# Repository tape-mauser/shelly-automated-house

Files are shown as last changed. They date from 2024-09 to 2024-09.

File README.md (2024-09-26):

# Shelly Automated Exhibition House

The project is fully completed and operational. However, the documentation is still a work in progress. We are actively working on providing detailed instructions, schematics, and additional information. Please stay tuned for updates.

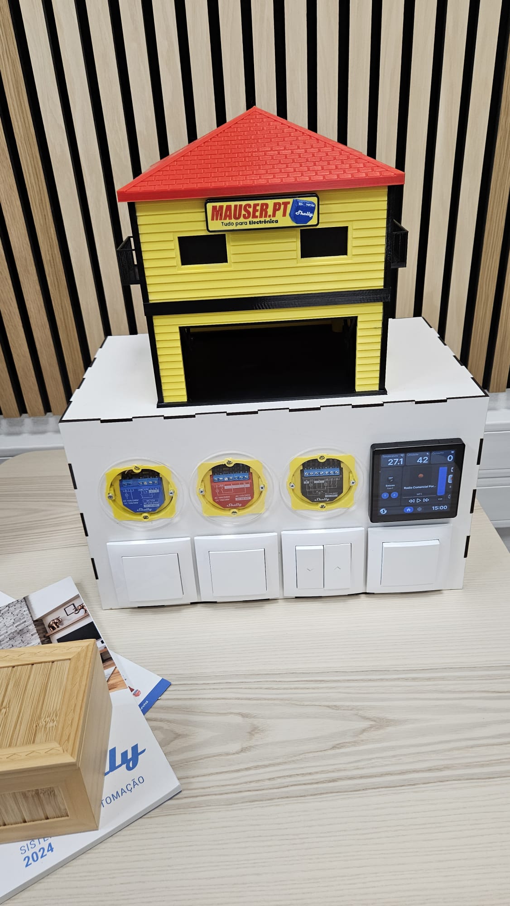
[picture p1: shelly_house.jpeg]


Welcome to the Automated Exhibition House project! This repository showcases a fully functional smart home setup using Shelly modules. The house is equipped with four Shelly modules, which control the gate, shutters, and lighting, providing an automated and seamless experience.

Watch the demonstration video below:

[Demo Video](https://youtu.be/CE9VABJTA8k)

## Project Overview
This project demonstrates the integration of IoT technology in a modern exhibition house setting. The key features include:

Automated Gate: The gate can be controlled remotely, allowing for easy access and enhanced security.
Smart Shutters: Control the shutters automatically or remotely to adjust the light and privacy levels in the house.
Lighting Control: The house's lighting system is fully automated, providing customized lighting scenes based on time or user preferences.
Modules Used
### Shelly plus 1PM: Utilized for the lighting system, enabling smooth dimming and on/off control.
### Shelly plus 2PM: Deployed for managing the shutters, allowing for both automation and manual control.
### Shelly Plus 1: Used to control the gate, ensuring precise and reliable operation. 
### Shelly wall display: Provides a user-friendly interface for monitoring and controlling the entire system from a central location.

## How It Works
The house is connected through a local Wi-Fi network, where each Shelly module is configured via the Shelly app or a home automation platform like Home Assistant. Users can interact with the system through their smartphones or integrate it with voice assistants for hands-free control.

## Installation
Hardware Setup: Install the Shelly modules in the designated locations (gate, shutters, lights).
Configuration: Connect the modules to your Wi-Fi network using the Shelly app.
Automation: Set up automation rules and schedules based on your preferences.
Monitoring: Use the Shelly app or a home automation dashboard to monitor and control the system.
Contributing
We welcome contributions to enhance this project! Feel free to fork the repository, submit issues, or open pull requests.

## BOM

| Item | Quantity | Description | Size | Supplier | Link |
|:---|:---:|:---|:---:|:---:|:---:|
| Base | 1 | MDF | 1100x500x3mm | NA | |
| Dry Wall Box | 8 | electrical dry wall box | NA | Mauser.pt | https://mauser.pt/catalog/product_info.php?products_id=302-0743 |
| Shelly plus 2PM | 1 | Shelly plus 2PM | NA | Mauser.pt  |https://mauser.pt/catalog/product_info.php?products_id=095-0483 |
| Shelly plus 1PM | 1 | Shelly plus 1PM | NA | Mauser.pt |https://mauser.pt/catalog/product_info.php?products_id=096-3331 |
| Shelly plus 1 | 1 | Shelly plus 1 | NA | Mauser.pt |https://mauser.pt/catalog/product_info.php?products_id=096-3327 |
| Shelly wall display | 1 | Shelly wall display | NA | Mauser.pt  |https://mauser.pt/catalog/product_info.php?products_id=302-3545 |
| Relay 230v | 4 | Relay 230v | NA | Mauser.pt |https://mauser.pt/catalog/product_info.php?products_id=083-0127|
| Node mcu esp32 |  1 |  Node mcu esp32 | NA |Mauser.pt |https://mauser.pt/catalog/product_info.php?products_id=096-7620|
| Power Supply | 1 |  Power Supply | NA | Mauser.pt | https://mauser.pt/catalog/product_info.php?products_id=035-2961 |
| IEC panel | 1 |  IEC panel | NA | Mauser.pt | https://mauser.pt/catalog/product_info.php?products_id=011-0459 |
| Power cord | 1 | Power cord | NA |Mauser.pt | https://mauser.pt/catalog/product_info.php?products_id=047-2090|
|  Blue Wire | 10MTR |Blue Wire | 1,5mm | Mauser.pt |  https://mauser.pt/catalog/product_info.php?products_id=016-0413  |
| Black Wire | 10MTR |  Black Wire | 1,5mm | Mauser.pt | https://mauser.pt/catalog/product_info.php?cPath=1874_56_646_2747_3511&products_id=016-0414 |
| Yellow/green Wire | 0,5MTR | Yellow/green Wire | 1,5mm | Mauser.pt | https://mauser.pt/catalog/index.php?cPath=1874_56_646_2747_3511 |
| 3Pair alarm cable | 10MTR | 3Pair alarm cable | 0,22mm/0,75mm  |  Mauser.pt |https://mauser.pt/catalog/product_info.php?cPath=1874_56_1504&products_id=016-0275  |
| Wire terminal | 30 | Wire terminal | 1,5mm | Mauser.pt | https://mauser.pt/catalog/product_info.php?products_id=011-0529 |
| servo motor | 2 | Servo Motor | | Mauser.pt | https://mauser.pt/catalog/product_info.php?products_id=096-6268 |
| Led strip | 1 | Led Strip | | Mauser.pt | https://mauser.pt/catalog/product_info.php?products_id=306-5426 |
| Belt | 1 | Servo Belt gate | |  Mauser.pt | https://mauser.pt/catalog/product_info.php?products_id=037-1095 |
| Pressure switch |  1 | (gate) | | Mauser.pt | https://mauser.pt/catalog/product_info.php?cPath=570_572_855_3342_1007_3326&products_id=302-1632 |
| Light switch |  2 | (lights) | | Mauser.pt | https://mauser.pt/catalog/product_info.php?products_id=302-1503 |
| Shutters switch |  1 | (shutters) | | Mauser.pt | https://mauser.pt/catalog/product_info.php?products_id=302-1530 |
| Shutters key | 1 | | | Mauser.pt | https://mauser.pt/catalog/product_info.php?cPath=570_572_855_3342_1008_3338&products_id=302-1531 |
| Switch key | 3 | | | Mauser.pt | https://mauser.pt/catalog/product_info.php?products_id=302-1504 |
| Switch frame | 1 | | | Mauser.pt | https://mauser.pt/catalog/product_info.php?products_id=302-1513 |
| Transparent cover | 1 | 3 covers to prevent electric shock|400x100x3mm| NA |  |
| Fundação Lateral | 1 | 3d printed Part |  160gr | NA |  |
| Paredes RC com portão e porta | 1 | 3d printed Part | 280gr | NA |  |
| Chão | 1 | 3d printed Part | 120gr | NA |  |
| Paredes com Janelas e varandas | 1 |3d printed Part | 340gr |NA |  |
| Telhado | 1 | 3d printed Part | 550gr | NA |  |
| Suporte de servo fundo | 1 | 3d printed Part | 15gr | NA |  |
| Portao casa impressa | 1 |  3d printed Part | 15gr | NA |  |
| cobertura portao | 1 | 3d printed Part | 15gr | NA |  |
| Varanda | 2 |3d printed Part | 20gr | NA |  |
| Porta | 1 | 3d printed Part | 10gr | NA |  |
| janela interior estores | 2 | 3d printed Part | 10gr | NA |  |
| janela pequena | 2 | 3d printed Part multicolor | 20gr | NA |  |
| janela grande | 1 | 3d printed Part multicolor | 20gr | NA |  |
| estore | 1 | 3d printed Part | 10gr | NA |  |
| reclame | 1 | 3d printed Part multicolor | 20gr | NA |  |
| polia | 1 | 3d printed Part | 5gr | NA |  |
| polia servo | 2 | 3d printed Part | 5gr | NA |  |
|suporte de shelly | 3 | 3d printed Part | 35gr | NA |  |
|cantos | 8 | 3d printed Part | 10gr | NA |  |
|M3 Screws | 8 | | 16mm | NA |  |
|M3 Nuts | 4 | | | NA |  |

## 230v diagram

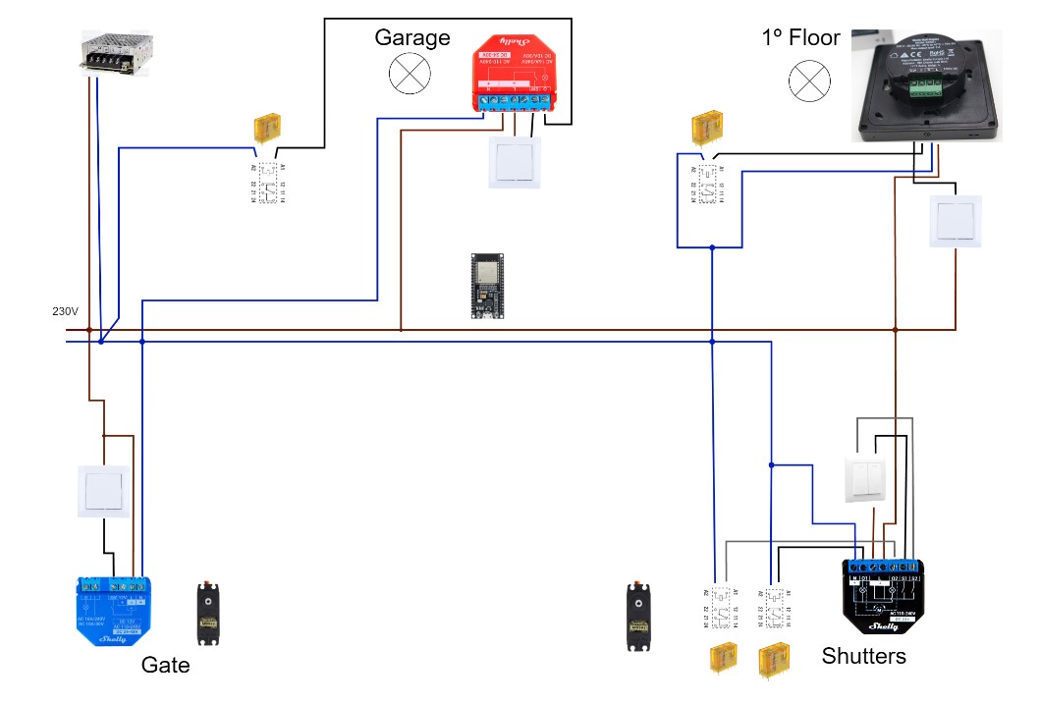
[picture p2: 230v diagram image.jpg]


You can view or download the full documentation in [this PDF file](./230v_shelly_diagram.pdf).

## 5v diagram

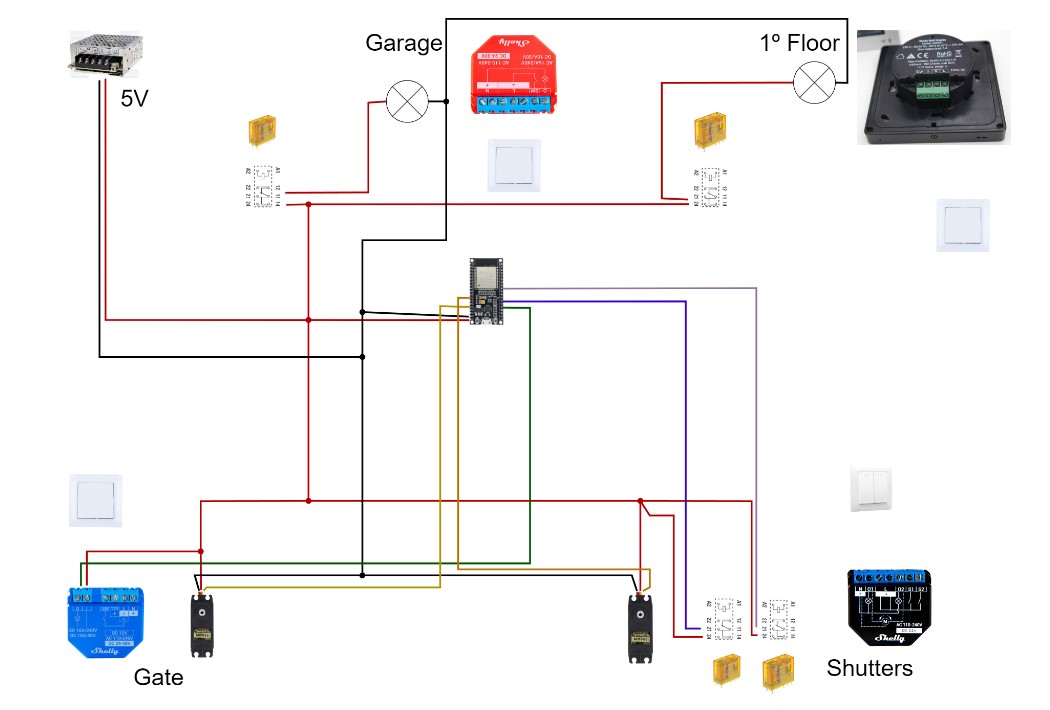
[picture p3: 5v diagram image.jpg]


You can view or download the full documentation in [this PDF file](./5v_shelly_diagram.pdf).

## ESP32 Code

use the ESP32servo by Kevin Harrington, John K. Bennett V 1.2.1  library
and esp32 by Espressif Systems V 2.0.17 Board manager 

ESP32 Dev Module

## License
This project is licensed under the MIT License. See the LICENSE file for more details.

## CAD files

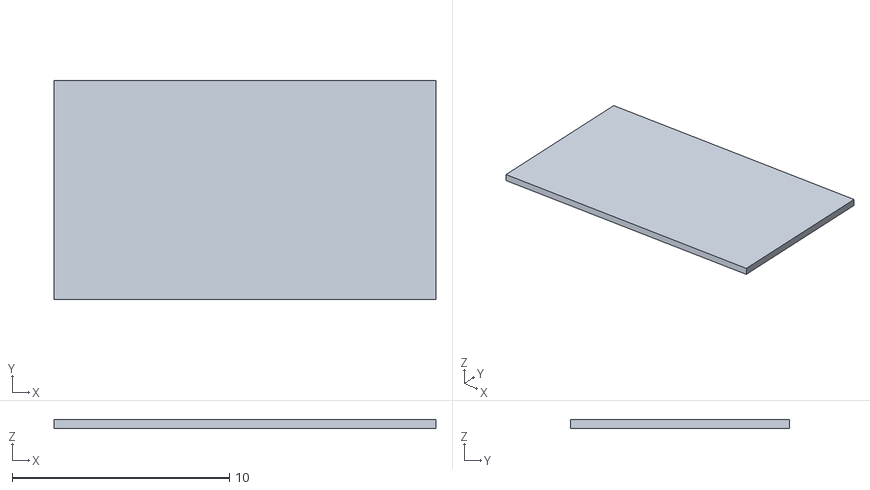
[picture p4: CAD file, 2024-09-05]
Multicolor STL's/Janela interior estores/Janela_interior_estores_Janela_interior_estores v1_Component1_1_Body3.stl
17.6 x 10.1 x 0.4

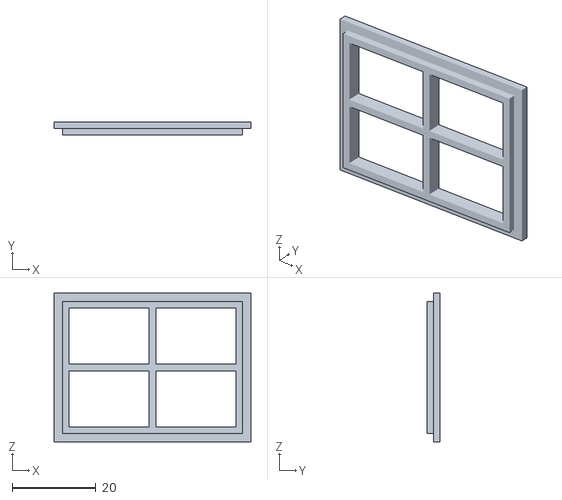
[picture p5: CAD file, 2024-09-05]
Multicolor STL's/janela pequena/janela pequena_janela pequena v2_Body1.stl
47.0 x 3.20 x 35.5

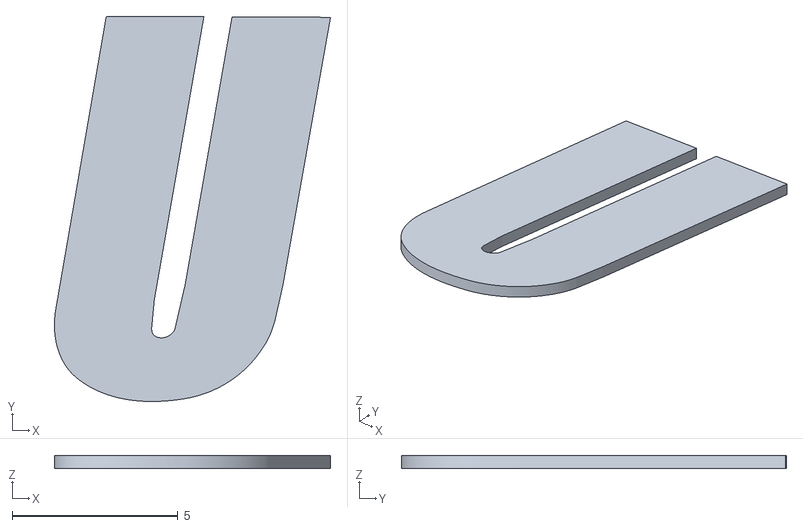
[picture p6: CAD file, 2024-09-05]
Multicolor STL's/reclame/reclame casa_reclame casa v2_Vermelho_1_Body2.stl
8.33 x 11.6 x 0.4

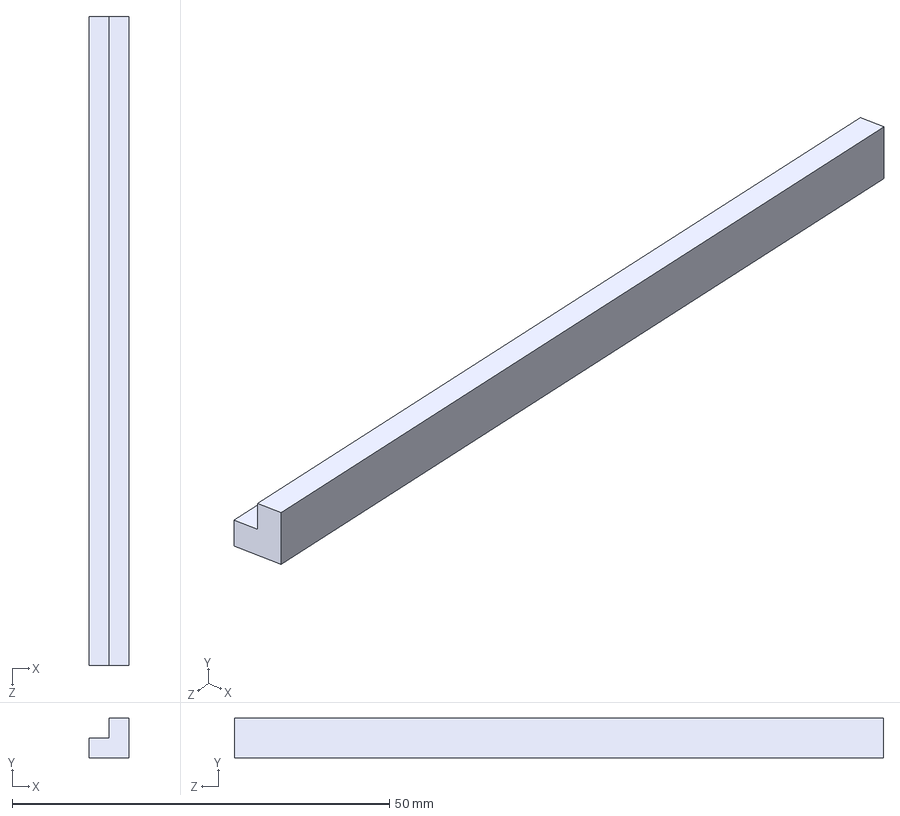
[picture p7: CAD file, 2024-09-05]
STEP's/cantos.STEP
5.25 x 5.25 x 86.0 mm

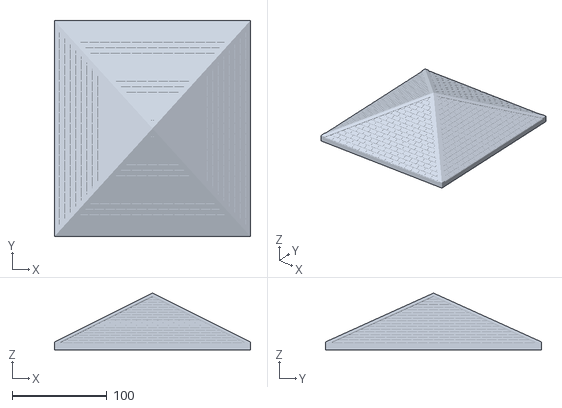
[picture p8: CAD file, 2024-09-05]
STL's/telhado.STL
206.8 x 227.8 x 60.0

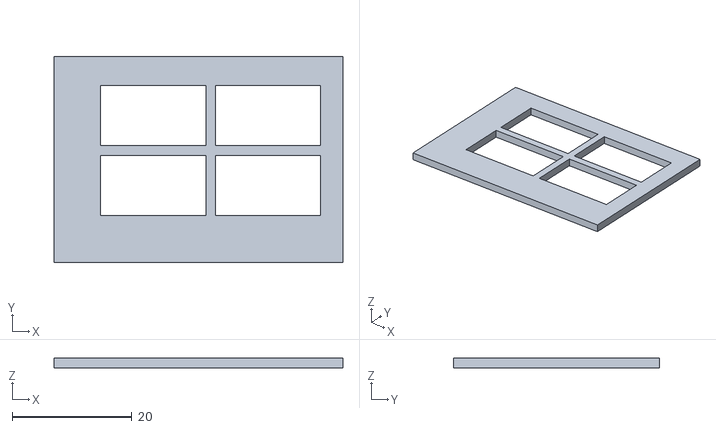
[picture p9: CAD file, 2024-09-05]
Multicolor STL's/Janela interior estores/Janela_interior_estores_Janela_interior_estores v1_Body1.stl
48.3 x 34.4 x 1.60

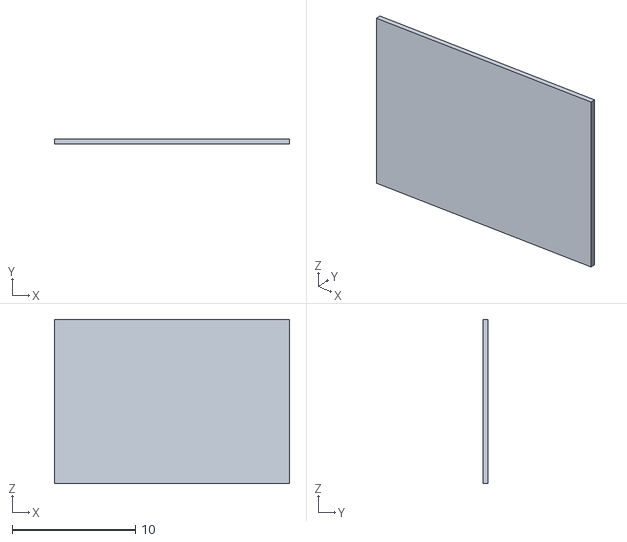
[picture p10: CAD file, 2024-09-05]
Multicolor STL's/janela pequena/janela pequena_janela pequena v2_Component1_1_Body4.stl
19.1 x 0.4 x 13.3

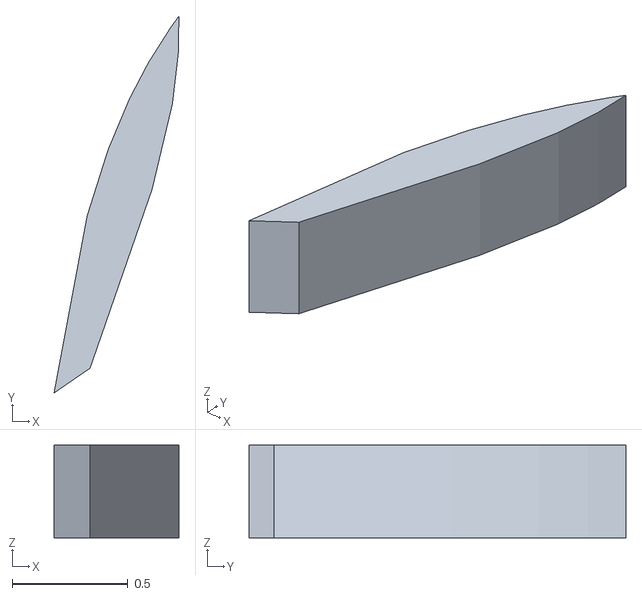
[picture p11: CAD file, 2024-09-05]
Multicolor STL's/reclame/reclame casa_reclame casa v2_Branco_1_Body2.stl
0.54 x 1.63 x 0.4

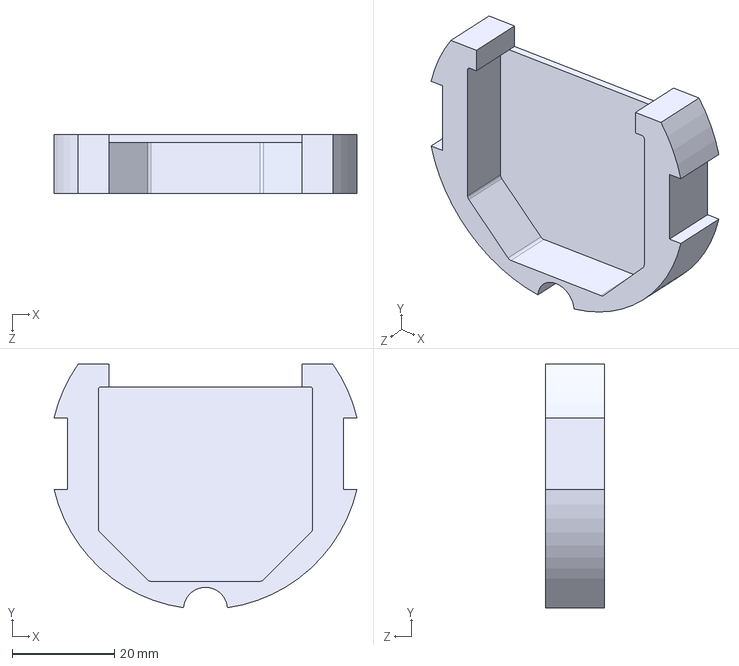
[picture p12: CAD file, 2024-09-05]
STEP's/suporte de shelly.STEP
59.4 x 47.7 x 11.6 mm

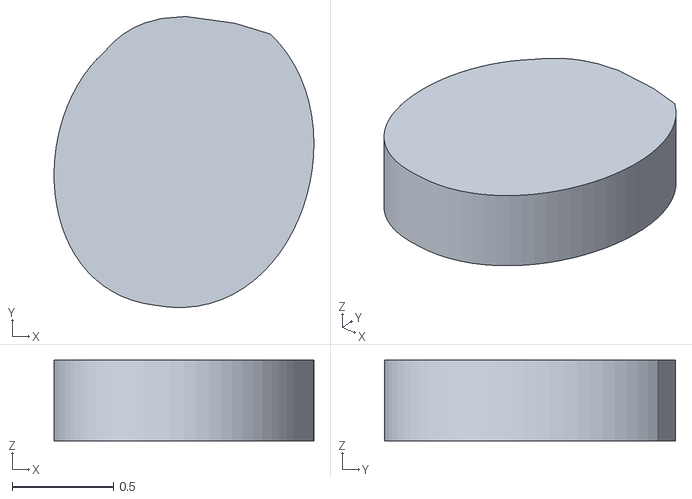
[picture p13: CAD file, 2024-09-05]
Multicolor STL's/reclame/reclame casa_reclame casa v2_Branco_1_Body11.stl
1.28 x 1.44 x 0.4

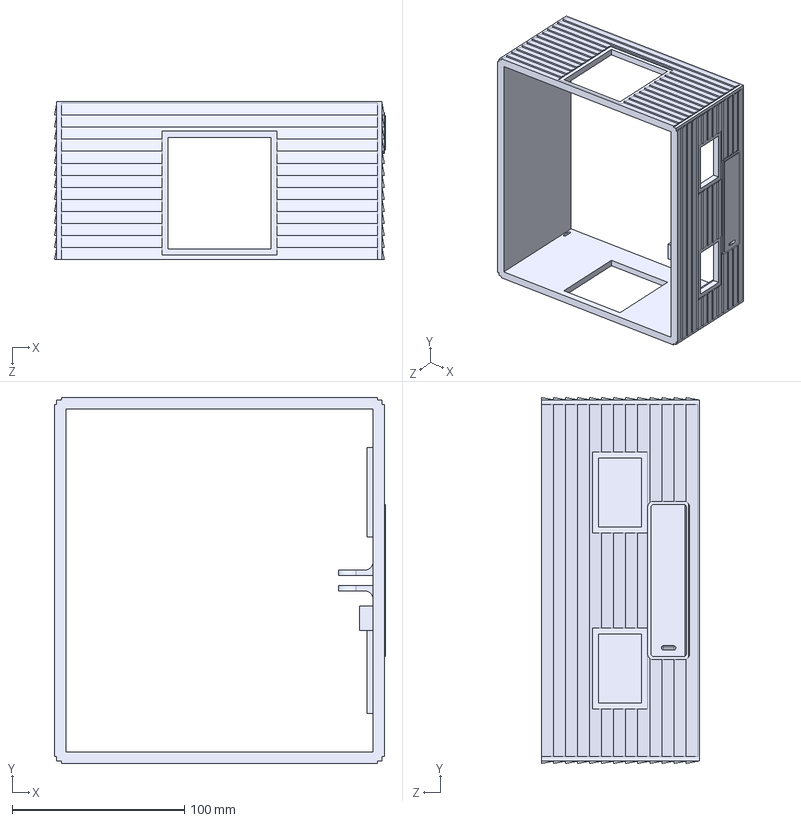
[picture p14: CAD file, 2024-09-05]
STEP's/Paredes com janelas e varandas.STEP
192.4 x 212.8 x 92.0 mm

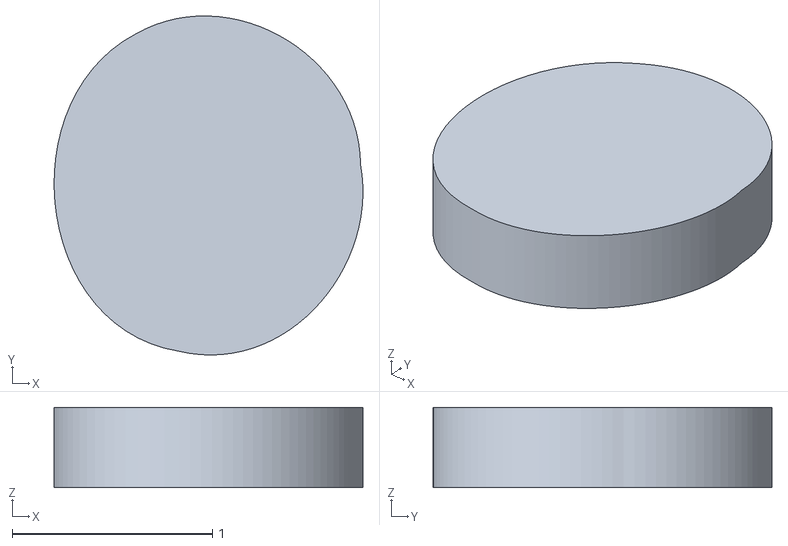
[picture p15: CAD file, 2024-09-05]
Multicolor STL's/reclame/reclame casa_reclame casa v2_Amarelo_1_Body5.stl
1.54 x 1.69 x 0.4

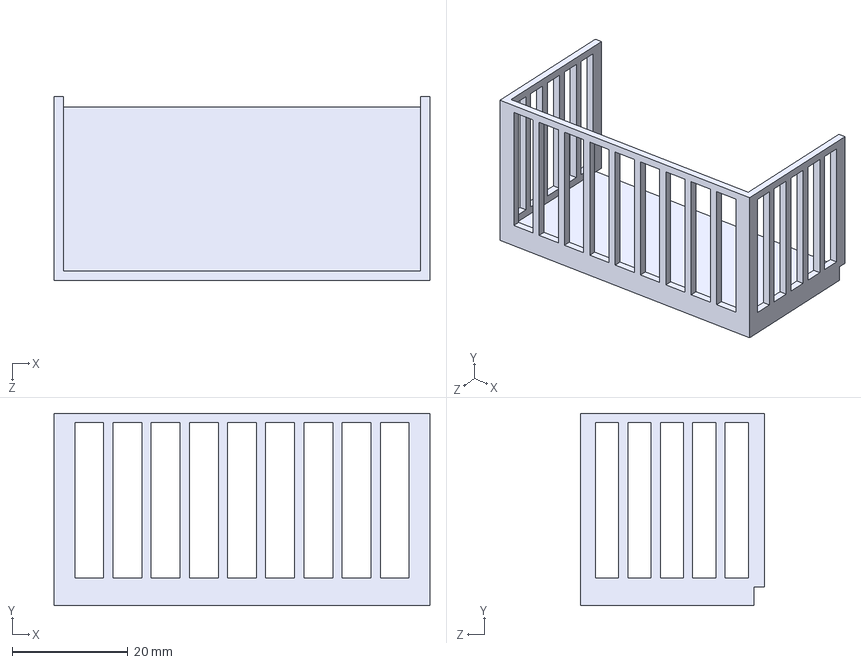
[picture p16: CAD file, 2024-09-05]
STEP's/varanda.STEP
65.0 x 33.2 x 31.8 mm

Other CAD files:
dxf files.dxf
Multicolor STL's/Janela interior estores/Janela_interior_estores_Janela_interior_estores v1_Component1_1_Body4.stl
Multicolor STL's/janela pequena/janela pequena_janela pequena v2_Component1_1_Body3.stl
Multicolor STL's/Janela interior estores/Janela_interior_estores_Janela_interior_estores v1_Component1_1_Body2.stl
Multicolor STL's/janela pequena/janela pequena_janela pequena v2_Component1_1_Body2.stl
Multicolor STL's/Janela interior estores/Janela_interior_estores_Janela_interior_estores v1_Component1_1_Body1.stl
Multicolor STL's/janela pequena/janela pequena_janela pequena v2_Component1_1_Body1.stl
Multicolor STL's/reclame/reclame casa_reclame casa v2_Amarelo2_1_Body1.stl
Multicolor STL's/reclame/reclame casa_reclame casa v2_Amarelo_1_Body1.stl
Multicolor STL's/reclame/reclame casa_reclame casa v2_Amarelo_1_Body10.stl
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

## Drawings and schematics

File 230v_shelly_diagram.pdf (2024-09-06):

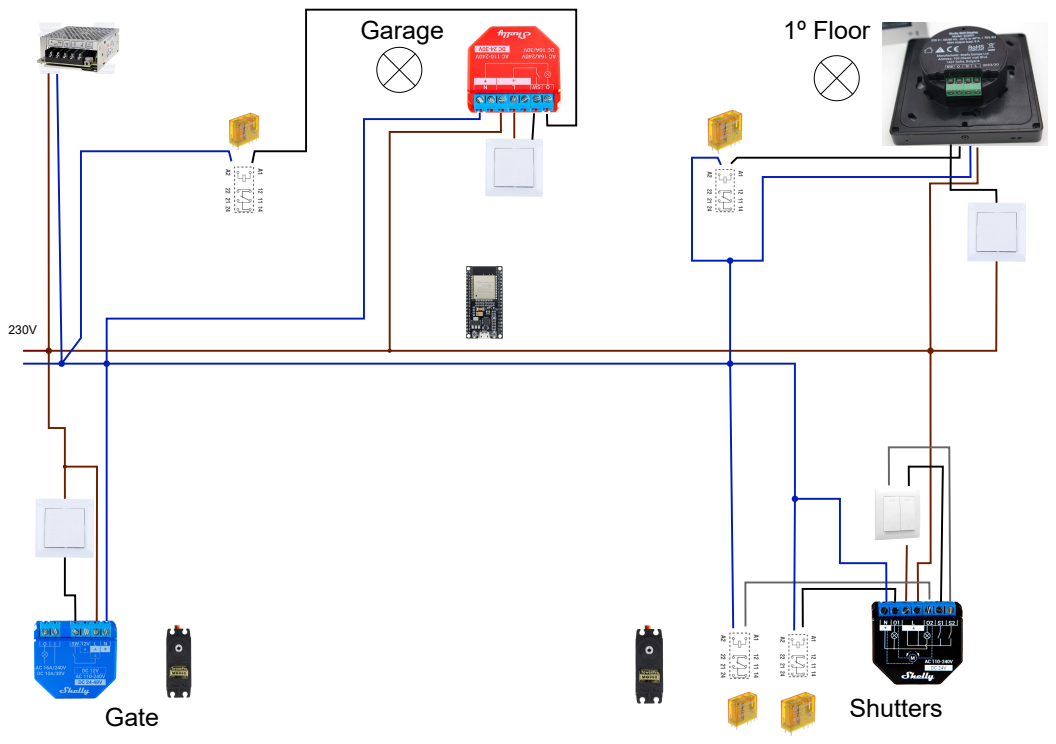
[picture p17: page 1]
Gate; Shutters; Garage; 1º Floor

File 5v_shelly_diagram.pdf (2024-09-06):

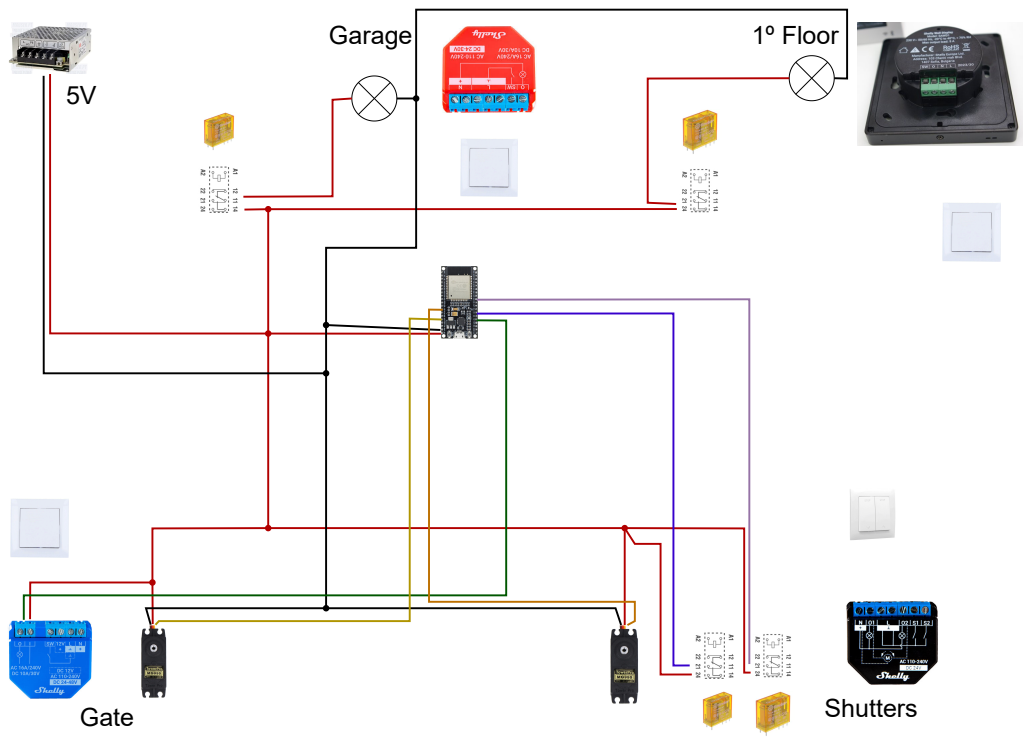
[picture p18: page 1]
Gate; Shutters; Garage; 1º Floor

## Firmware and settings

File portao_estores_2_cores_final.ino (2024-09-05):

#include <ESP32Servo.h>
#include "freertos/FreeRTOS.h"
#include "freertos/task.h"

// Código 1
Servo servo1;                // Cria um objeto Servo
const int servoPin1 = 13;    // Pino onde o servo está conectado
const int buttonPin1 = 2;    // Pino onde o botão está conectado
int buttonState1 = 0;        // Variável para armazenar o estado do botão
bool servoAtInitialPosition1 = true; // Variável para verificar se o servo está na posição inicial
int servoPosition1 = 140;      // Variável para controlar a posição do servo

// Código 2
Servo servo2;                // Cria um objeto Servo
const int servoPin2 = 14;    // Pino onde o servo está conectado
const int buttonPin2_180 = 4;  // Pino onde o botão 2 está conectado
const int buttonPin2_0 = 18;    // Pino onde o botão 3 está conectado
int buttonState2_180 = 0;     // Variável para armazenar o estado do botão 2
int buttonState2_0 = 0;       // Variável para armazenar o estado do botão 3
int servoPosition2 = 0;       // Variável para controlar a posição do servo

void task1(void *parameter) {
  servo1.attach(servoPin1);  // Anexa o servo ao pino 13
  pinMode(buttonPin1, INPUT_PULLDOWN);  // Define o pino do botão como entrada com pull-down interno
  servo1.write(servoPosition1);  // Define a posição inicial do servo como 140 graus

  for (;;) {
    buttonState1 = digitalRead(buttonPin1);  // Lê o estado do botão

    if (Serial.available() > 0) { // Verifica se há dados disponíveis para leitura no serial
      int data = Serial.read(); // Lê o dado serial
      // Mova o servo para a posição recebida
      servo1.write(data);
    }

    if (buttonState1 == HIGH) {  // Verifica se o botão foi pressionado
      delay(50);  // Debounce do botão
      if (digitalRead(buttonPin1) == HIGH) {
        if (servoAtInitialPosition1) {
          for (int pos = servoPosition1; pos >= 0; pos -= 1) { // Move o servo gradualmente para 0 graus
            servo1.write(pos);
            delay(50); // Ajuste o atraso para controlar a velocidade do movimento
          }
        } else {
          for (int pos = servoPosition1; pos <= 140; pos += 1) { // Move o servo gradualmente para 140 graus
            servo1.write(pos);
            delay(50); // Ajuste o atraso para controlar a velocidade do movimento
          }
        }
        servoPosition1 = 140 - servoPosition1; // Inverte a posição do servo
        servoAtInitialPosition1 = !servoAtInitialPosition1; // Alterna o estado do servo
        while (digitalRead(buttonPin1) == HIGH) {}  // Aguarda até que o botão seja liberado
      }
    }
    vTaskDelay(10 / portTICK_PERIOD_MS); // Pequeno delay para evitar a sobrecarga da CPU
  }
}

void task2(void *parameter) {
  servo2.attach(servoPin2);  // Anexa o servo ao pino 2
  pinMode(buttonPin2_180, INPUT_PULLDOWN);  // Define o pino do botão 2 como entrada com pull-down interno
  pinMode(buttonPin2_0, INPUT_PULLDOWN);    // Define o pino do botão 3 como entrada com pull-down interno
  servo2.write(servoPosition2);  // Define a posição inicial do servo como 0 graus

  for (;;) {
    buttonState2_180 = digitalRead(buttonPin2_180);  // Lê o estado do botão 2
    buttonState2_0 = digitalRead(buttonPin2_0);      // Lê o estado do botão 3

    if (buttonState2_180 == HIGH) {  // Verifica se o botão 2 foi pressionado
      Serial.println("Botão 2 (180º) pressionado"); // Mensagem de depuração
      if (servoPosition2 < 180) {
        servoPosition2 += 1;  // Incrementa a posição do servo
        servo2.write(servoPosition2);
        delay(25); // Ajuste o atraso para controlar a velocidade do movimento
      }
    }

    if (buttonState2_0 == HIGH) {  // Verifica se o botão 2 foi pressionado
      Serial.println("Botão 3 (0º) pressionado"); // Mensagem de depuração
      if (servoPosition2 > 0) {
        servoPosition2 -= 1;  // Decrementa a posição do servo
        servo2.write(servoPosition2);
        delay(25); // Ajuste o atraso para controlar a velocidade do movimento
      }
    }

    vTaskDelay(10 / portTICK_PERIOD_MS); // Pequeno delay para evitar a sobrecarga da CPU
  }
}

void setup() {
  Serial.begin(115200); // Inicia a comunicação serial

  // Cria as tarefas para cada código nos diferentes núcleos
  xTaskCreatePinnedToCore(
    task1,     // Função da tarefa
    "Task1",   // Nome da tarefa
    10000,     // Tamanho da pilha (em palavras)
    NULL,      // Parâmetro para passar para a tarefa
    1,         // Prioridade da tarefa
    NULL,      // Handle da tarefa (opcional)
    0);        // Núcleo onde a tarefa será executada

  xTaskCreatePinnedToCore(
    task2,     // Função da tarefa
    "Task2",   // Nome da tarefa
    10000,     // Tamanho da pilha (em palavras)
    NULL,      // Parâmetro para passar para a tarefa
    1,         // Prioridade da tarefa
    NULL,      // Handle da tarefa (opcional)
    1);        // Núcleo onde a tarefa será executada
}

void loop() {
  // Deixe o loop vazio, pois as tarefas estão sendo executadas nos núcleos
}
